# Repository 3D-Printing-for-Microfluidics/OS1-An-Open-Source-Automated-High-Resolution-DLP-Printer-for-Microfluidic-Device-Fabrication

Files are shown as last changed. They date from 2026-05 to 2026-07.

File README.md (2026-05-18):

# **OS1:** An Open-Source, Automated, High-Resolution DLP Printer for Microfluidic Device Fabrication

Open Source 1 (OS1), an open-source, high-resolution, DLP-based vat photopolymerization platform for fabricating microfluidic devices. Microfluidic function is defined by interconnected negative features, i.e., void regions that form channels, chambers, valves, and other fluidic elements within the printed structure. Accurately producing these features requires high optical resolution, uniform exposure, precise build-surface alignment, and reliable focus control. OS1 addresses these requirements in an automated platform derived from more than 10 years of custom DLP printer development for microfluidics. The printer enables rapid fabrication of microfluidic devices with complex three-dimensional negative-feature geometries that are difficult to achieve using traditional cleanroom-based methods. To reduce dependence on specialized hardware expertise and custom calibration tools, OS1 includes automatic build-surface planarization, automated focus calibration, active focus correction across the build area using a confocal displacement sensor, light-engine power correction using a fiber-optic photodiode sensor, and grayscale image correction for improved irradiance uniformity. These capabilities support repeatable, high-quality fabrication while making advanced microfluidic 3D printing more accessible to other research groups.

This repository is the home to the digital design files for the OS1's hardware, the standalone instruction manual, and the bill of materials.

## CAD

In the CAD folder, step files for the entire printer assmebly and each custom component are included. For parts that are FDM printed, a .3mf file is included. For aluminum parts and polycarbonate parts that are to be cut on a CNC waterjet, a .dxf "Tetris" layout file is included. There are also folders containing the design and manufacturing files for 2 custom printed circuit boards.

## Bill of Materials

The Bill of Materials is contained in a Microsoft Excel spreadsheet (.xlsx). It is oraganized into subassembly groups to match the instruction manual.

## Supplemental

The Visitech LRS WQ light engine utilized in this platform has been discontinued and replaced with an LRS WQ Plus light engine. This new version is not compatible with the current OS1 software and has not been validated with our platform; however, the full STEP assembly for the updated version and an alternate instruction manual are available in the supplemental information. Note on printer software: the LRS WQ Plus is a major revision of the LRS platform and uses a new communication protocol from the previous version. To implement the new LRS WQ Plus, a new hardware driver will need to be written which does not rely on HDMI data transfer from the Raspberry Pi.

Included in the supplemental materials is also a set of videos detailing specific parts of printer construction, operation, and maintenance.

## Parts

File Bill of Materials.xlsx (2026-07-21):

Subsystem | Designator | Component (Description) | Number | Cost Per Unit ($) | Total Cost ($) | Source of Materials | Total Cost
General Assembly |  | (Item #: ) |  |  |  |  | 69766.73
 | M6 x 16 Screws | Alloy Steel Socket Head Screw M6x16 (Item #: 91290A321) | 2 | 16.63 | 33.26 | https://www.mcmaster.com/91290A321/
 | M4 x 10 Button Head Screws | 316 Stainless Steel Button Head Hex Drive Screws (Item #: 94500A227) | 2 | 14.6 | 14.6 | https://www.mcmaster.com/94500A227/
 | M4 Hex Nut | Medium-Strength Steel Thin-Profile Hex Nut (Item #: 90695A035) | 1 | 2.73 | 2.73 | https://www.mcmaster.com/90695A035/
 | M2-M6 Assorted Screw and Nut Set | This contains assorted screws that will be used as fasteners in the 3D printer. Hapric 2160 Pcs Metric Screw Assortment Metric Bolts M2 M3 M4 M5 M6 Nuts and Bolt Kit, 12.9 Alloy Steel Black Zinc Plated Hex Socket Head Screws Nuts Bolts and Washers Set | 1 | 22.99 | 22.99 | https://a.co/d/07h6Lx55
 | 6061 Aluminum Block For Build Platform | 6061 Aluminum Block to be milled for Build Platform | 2 in x 2 in x 3 in (50.8 mm x 50.8 mm x 76.2 mm) | N/A |  | Online Metal Supplier or Local Metal Supplier
 | 6061 Aluminum Block For Resin Tray | 6061 Aluminum Block to be milled for Resin Tray | 1.5 in x 4.5 in x 7.5 in (38.1 mm x 114.3 mm x 190.5 mm) | N/A |  | Online Metal Supplier or Local Metal Supplier
 | 0.5" 6061 Aluminum | 0.5 inch (12.7mm) thick 6061 aluminum plate | 3.281 ft x 3.281 ft (1 m x 1 m), 10.765 ft^2 (1 m^2) | N/A | 500 | https://www.midweststeelsupply.com/store/6061aluminumplate
 | 18 Guage 6061 Aluminum Sheet | 18 guage (1 mm thick) 6061 aluminum sheet for fiber optic mounting plate | 35 mm x 35 mm |  |  | Online Metal Supplier or Local Metal Supplier
 | Invar Legs | INVAR Rod 0.75 Diameter x 12 in length | 6 | 76 | 456 | https://www.efineametals.com/controlled-expansion-alloys/invar-36-pernifer-36-nilo-36-invar-steel/invar-pernifer-nilo-36-rod-bar-sheet-plate/
 | M6 Spacers | Aluminum Unthreaded Spacer 13 mm OD, 4 mm Long, for M6 Screw Size (Item #: 94669A162) | 6 | 0.94 | 5.64 | https://www.mcmaster.com/94669A162/
 | DIN Rail | Steel DIN 3 Rail, 5-7/8" Length (Item #: 8961K86) | 1 | 4.47 | 4.47 | https://www.mcmaster.com/8961K86/
 | Hose Clamp | Worm-Drive Clamps for Firm Hose and Tube, Steel Screw, 1/2" Band Width, 1-1/16" to 2" Clamp ID (Item #: 5415K17) | 1 | 12.63 | 12.63 | https://www.mcmaster.com/5415K17/
Control Electronics
 | USB Hub | UGREEN USB 3.0 Hub, 4 Ports USB A Splitter Ultra-Slim USB Expander for Mouse, Keyboard, Flash Drive, U Disk, Printer Compatible with Laptop, Desktop PC, Xbox, PS5, and More | 1 | 6.96 | 6.96 | https://a.co/d/0eLZbc51
 | Ethernet Cables | Cable Matters 10Gbps 5-Pack Snagless Cat 6 Ethernet Cable - 5ft, Cat 6 Cable, Cat6 Cord, Ethernet Cord, Black | 4 | 14.99 | 14.99 | https://a.co/d/03ATOEky
 | USB-A to Micro USB Cables | Amazon Basics 2-Pack USB-A to Micro USB Cable, Data Transfer, Android Charger, 480Mbps Transfer Speed, Gold-Plated Plugs, USB 2.0, 3 Foot, Black | 2 | 7.99 | 7.99 | https://a.co/d/08tfeqxj
 | 2-pin MOLEX connectors | 2 Rectangular Connectors - Housings Receptacle White 0.100" (2.54mm) (Item #: 900-0022013027-ND) | 3 | 0.1 | 3 | https://www.digikey.com/short/2q20hb45
 | AWG Crimp | Non-Gendered Contact Tin 22-30 AWG Crimp (Item #: WM2623-ND) | 6 | 0.14 | 0.84 | https://www.digikey.com/short/h277nhrp
 | PCB Connector Header | Connector Header Through Hole 2 position 0.156" (3.96mm) (Item #: WM50008-02-ND) | 3 | 0.55 | 1.65 | https://www.digikey.com/short/j205fpr2
 | Raspberry Pi 5 | SBC 2.4GHZ 4 CORE 8GB PI 5 (Item #: 2648-SC1432-ND) | 1 | 175 | 175 | https://www.digikey.com/short/ft70prjf
 | Raspberry Pi Active Cooler | Heat Sink Raspberry Pi 5 Aluminum (Item #: 2648-SC1148-ND) | 1 | 5 | 5 | https://www.digikey.com/short/919jzb3j
 | NVMe Base | Pimoroni NVMe Base for Raspberry Pi 5 - PIM699 (Item #: 5845) | 1 | 19.95 | 19.95 | https://www.adafruit.com/product/5845
 | Raspberry Pi SSD | Kingston NV3 1TB M.2 2280 NVMe SSD, PCIe 4.0 Gen 4x4, Up to 6000 MB/s, SNV3S/1000G. NOTE: 1 TB is not necessary if you will not be doing a lot of printing. We have one because we needed the additional storage. | 1 | 164.99 | 164.99 | https://a.co/d/02vxUVt9
 | Raspberry Pi Power Supply | Official Raspberry Pi 27W PD Power Supply 5.1V 5A with USB C (Item #: 5814) | 1 | 14.04 | 14.04 | https://www.adafruit.com/product/5814
 | Teensy 4.0 | 4.0 (Headers) | 2 | 30.05 | 60.1 | https://www.amazon.com/Teensy-4-0-With-Pins/dp/B08259KDHY/ref=sr_1_3
 | PDU | StarTech.com 16 Outlet Horizontal 1U Rack Mount PDU Power Strip | 1 | 80.1 | 80.1 | https://www.amazon.com/StarTech-com-Rackmount-Outlets-Surge-Protection/dp/B003GSGNE0?th=1
 | Resistors | 4.7 kOhm and 10 kOhm resistor | 1 | 5.99 | 5.99 | https://a.co/d/08zMVh81
Enclosure
 | Enclosure Polycarbonate | Polycarbonate Clear Plastic Sheet 24" X 48 X 0.118 (1/8") | 1 | 47.22 | 47.22 | https://a.co/d/i2hpSBR
 | UV Film | HOHOFILM 60"x20" Colored Window Film Clear Decorative Glass Tint Sun Blocking Heat Control Self Adhesive Window Tint | 1 | 16.9 | 16.9 | https://a.co/d/div4S9N
 | Hinges | Mini Leaf Hinge (Item #: RPC2430-ND) | 5 | 3.35 | 16.77 | https://www.digikey.com/en/products/detail/essentra-access-solutions/129912/7688848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
 | Rubber Stopper | Load-Rated Adhesive-Back Sorbothane Bumper (Item #: 8215K215) | 2 | 7.6 | 15.2 | https://www.mcmaster.com/8215K215/
Resin Tray
 | M4 x 12, 90 degree | M4, coarse, 25, countersink, 90 degree (Item #: 91294A192) | 1 | 6.38 | 6.38 | https://www.mcmaster.com/91294a192/
 | Key Locking Inserts | 18-8 Stainless Steel Key-Locking Inserts with Thin Wall, M4 x 0.7 mm Thread, 5.25 mm Installed Length (Item #: 93715A345) | 5 | 12.46 | 49.9 | https://www.mcmaster.com/93715A345/
 | Kinematic Ball Mounts | uxcell 1/2-inch Ceramic Bearing Balls ZrO2 Zirconium Oxide Ball G5 Precision | 3 | 8.79 | 26.37 | https://a.co/d/8nKZhx9
 | Glass | Large Microscope Slides, 3 inx 4 in (Item #: #3040-50) | 1 | 97.5 | 97.5 | https://brainresearchlab.com/product/large-slides/
 | Clamps | Low-Profile Hold-Down Toggle Clamp (Item #: 5091A11) | 2 | 15.2 | 30.4 | https://www.mcmaster.com/5091A11/
 | O-Rings | Chemical-Rst Viton® Fluoroelastomer O-Ring Super-Resilient, 2 mm Wide, 94 mm ID (Item #: 1295N282) | 1 | 6.44 | 6.44 | https://www.mcmaster.com/1295N282/
 | Torque Screw-Driver | Screw driver for resin tray screws (Item #: 431-28413-ND) | 1 | 137.98 | 137.98 | https://www.digikey.com/en/products/detail/wiha/28413/10126229?s=N4IgTCBcDaICwGYCMBaMAOOSEoHIBEQBdAXyA
 | Blade Hex | Blad Hex for screw driver: 2.5MM 6.89" (Item #: 431-1302-ND) | 1 | 8.98 | 8.98 | https://www.digikey.com/en/products/detail/wiha/28547/1987925
 | Squeegee For Film Application | 4 Inch Mini Squeegee Silicone Squeegee with Rubber Water Blade, Anti-Slip Handle | 1 | 10.55 | 10.55 | https://a.co/d/0cAwyj2l
Build Platform
 | Planarization Screw | Alloy Steel Socket Head Screw Black-Oxide, M4 x 0.7 mm Thread, 110 mm Long (Item #: 91290A575) | 1 | 9.33 | 9.33 | https://www.mcmaster.com/catalog/131/3556/91290A575
 | Rivet Nut | Stainless Steel Twist-Resistant Rivet Nuts (Item #: 97467a666) | 1 | 8.07 | 8.07 | https://www.mcmaster.com/catalog/131/3790/97467A666
 | Alignment Pins | Linear Motion Shaft-- needs to be cut to size. (Item #: 1031K61) | 1 | 10.28 | 10.28 | https://www.mcmaster.com/catalog/131/1375/1031K61
 | M5 Alignment Screws | 18-8 Stainless Steel Low-Profile Socket Head Screws (Item #: 92855A528) | 1 | 12.71 | 12.71 | https://www.mcmaster.com/catalog/131/3574/92855A528
 | 5 mm Shaft Diameter Flanged Bearings | Flanged Sleeve Bearings (Item #: 2934T111) | 4 | 8.63 | 34.52 | https://www.mcmaster.com/catalog/131/1453/2934T111
 | 0.5 mm Brass Ring Shim | 0.5 mm Thick, 6 mm ID (Item #: 92678A631) | 1 | 10.3 | 10.3 | https://www.mcmaster.com/catalog/131/3720/92678A631
 | 0.2 mm Brass Ring Shim | 0.2 mm Thick, 6 mm ID (Item #: 92678A611) | 2 | 8.03 | 16.06 | https://www.mcmaster.com/catalog/131/3720/92678A611
 | Springs | 0.625" Long, 0.360" OD, 0.290" ID (Item #: 9657K656) | 1 | 13.16 | 13.16 | https://www.mcmaster.com/9657K656/
 | 5/32" Shaft Diameter Bronze Bearing | High-Strength 932 Bronze Flanged Sleeve Bearing for 5/32" Shaft Diameter and 1/4" Housing ID, 3/8" Long (Item #: 7815K804) | 1 | 19.3 | 19.3 | https://www.mcmaster.com/7815K804/
 | 0.2 mm Brass Shim Washer | 260-360 Brass Shim 0.2 mm Thick, 6 mm ID (Item #: 92678A611) | 2 | 8.03 | 16.06 | https://www.mcmaster.com/93715A345/
 | 0.5 mm Brass Shim Washer | 260-360 Brass Shim 0.5 mm Thick, 6 mm ID (Item #: 92678A631) | 1 | 10.3 | 10.3 | https://www.mcmaster.com/92678A631/
 | JB-Weld | J-B Weld 8265S Original Cold-Weld Steel Reinforced Epoxy - 2 oz. | 1 | 6.49 | 6.49 | https://a.co/d/09OcuKCe
Motion Stages
 | X-Stage | 150 mm Linear Translation Stage with Integrated Controller, Stepper Motor (Item #: LTS150C/M) | 1 | 3392.5 | 3392.5 | https://www.thorlabs.com/newgrouppage9.cfm?objectgroup_id=3961&pn=LTS150C/M#8110
 | Y-Stage | 300 mm Linear Translation Stage with Integrated Controller, Stepper Motor (Item #: LTS300C/M) | 1 | 3847.57 | 3847.57 | https://www.thorlabs.com/newgrouppage9.cfm?objectgroup_id=7652&pn=LTS300C/M#8109
 | Focus Stage | 25 mm (0.98") Low-Profile Motorized Translation Stage (Item #: MTS25/M-Z8) | 1 | 1177.03 | 1177.03 | https://www.thorlabs.com/newgrouppage9.cfm?objectgroup_id=3423&pn=MTS25/M-Z8#3005
 | Griffin Z-Stage with Power Supply and Galil Controller | LNS linear stage, 100mm travel, brushless servo motor, sinusoidal (Item #: LNS-100) | 1 | 6500 | 6500 | https://www.griffinmotion.com/shop/lns-100
 | X/Y Adapter Plate | XY Adapter Plate for LTS150C/M, LTS300C/M, LTS450C/M, or LTS600C/M Stages (Item #: LTSP1/M) | 1 | 89.61 | 89.61 | https://www.thorlabs.com/item/LTSP1_M
Auto Planarization
 | DC motor driver | MP6550 Single Brushed DC Motor Driver Carrier (Item #: 4733) | 1 | 5.95 | 5.95 | https://www.pololu.com/product/4733
 | Planarization motor | 227:1 Metal Gearmotor 25Dx56L mm MP 12V (Item #: 3233) | 1 | 33.95 | 33.95 | https://www.pololu.com/product/3233
 | Planarization Gears | 2303 Series Steel, MOD 0.8 Pinion Gear (4mm Round Bore, 15 Tooth) (Item #: 2303-0004-0015) | 2 | 9.95 | 19.89 | https://www.servocity.com/2303-series-steel-mod-0.8-pinion-gear-4mm-round-bore-15-tooth-/
 | Motor Bracket | 25D mm Metal Gearmotor Bracket Pair (Item #: 2676) | 1 | 10.95 | 10.95 | https://www.pololu.com/product/2676
Loadcell
 | 15 kg loadcell | ANYLOAD 108BA Aluminum Single Point Load Cell (Item #: 108BA) | 1 | 86 | 86 | https://tacunasystems.com/products/load-cells/single-point/anyload-108ba-aluminum-single-point-load-cell/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
 | Amplifier | (Item #: FSH03863) | 1 | 715 | 715 | https://www.futek.com/configure/advanced/fsh03863/1/0
 | Amplifier Power supply | (Item #: FSH04448) | 1 | 120 | 120 | https://www.futek.com/store/accessories/instrument-accessories/fsh04448
Tip-Tilt Assembly
 | Tip/Tilt Motors | 12 mm Travel DC Servo Motor Actuators (Item #: Z912) | 2 | 938.6 | 1877.2 | https://www.thorlabs.com/newgrouppage9.cfm?objectgroup_id=1882&pn=Z912#2497
 | Tip/Tilt Stage | KM200B/M - 73.7 mm x 73.7 mm Kinematic Platform Mount (Item #: KM200B/M) | 1 | 122.03 | 122.03 | https://www.thorlabs.com/thorproduct.cfm?partnumber=KM200B/M
 | K-Cubes | K-Cube Brushed DC Servo Motor Controller (Item #: KDC101) | 3 | 826.75 | 2480.25 | https://www.thorlabs.com/newgrouppage9.cfm?objectgroup_id=2419&pn=KDC101
 | K-Cube Dock | K-Cube USB Controller Hub (Item #: KEH3) | 1 | 662.5 | 662.5 | https://www.thorlabs.com/item/KEH3
 | Mirror | 75mm Square UV Enhanced Aluminum Coated, λ/10 Mirror (Item #: #84-426) | 1 | 360.4 | 360.4 | https://www.edmundoptics.com/p/75mm-square-uv-enhanced-aluminum-coated-lambda10-mirror/27522/
 | Keyence Sensor | Sensor head (70 mm ・Focused spot type) (Item #: CL-P070) | 1 | 2100 | 2100 | https://www.keyence.com/products/measure/laser-1d/cl-3000/models/cl-p070/?search_dl=1
 | Keyence Optical Unit | Optical unit (70 mm ・Focused spot type) (Item #: CL-P070N) | 1 | 4800 | 4800 | https://www.keyence.com/products/measure/laser-1d/cl-3000/models/cl-p070n/?search_dl=1
 | Keyence Sensor Controller | Ultra-compact switch-mode power supply (Item #: CL-3000) | 1 | 4300 | 4300 | https://www.keyence.com/products/measure/laser-1d/cl-3000/models/cl-3000/?search_dl=1
 | Keyence Power Supply | Ultra-compact switch-mode power supply (Item #: CA-U4 (CA-U4#)) (Power Supply Cable Item #: OP-99025) | 1 | 320 | 320 | https://www.keyence.com/products/measure/laser-2d/lj-s8000/models/ca-u4/?search_dl=1
 | Sticky Foam Tape | 3M 4032 Double Coated Urethane Foam Tape, Bonding, Attaching, Mounting, White, 0.5 in x 5 yd, 1 Roll | 1 | 8.29 | 8.29 | https://a.co/d/7Shym37
Photo Diode
 | Photodiode Sensor | Silicon Fiber Power Head, 350-1100nm, 5mW (Item #: S150C) | 1 | 381.34 | 381.34 | https://www.thorlabs.com/thorproduct.cfm?partnumber=S150C
 | USB Interface | USB Power and Energy Meter Interface (Item #: PM100USB) | 1 | 532.59 | 532.59 | https://www.thorlabs.com/thorproduct.cfm?partnumber=PM100USB
 | Bifurcated Fiber | Bifurcated Fiber Bundle, Ø50/125 Fiber, High OH, SMA, L=2m (Item #: BFY50HS02) | 1 | 474.23 | 474.23 | https://www.thorlabs.com/thorproduct.cfm?partnumber=BFY50HS02
 | Fiber Optic Adapter | Fiber Optic Connectors ADAPTER, SMA HALF-LENGTH (Item #: 523-905-120-5004) | 1 | 5.99 | 5.99 | https://www.mouser.com/ProductDetail/Amphenol-Fiber-Optics/905-120-5004-P?qs=7%2F6SraaimPRtTpADennAWQ%3D%3D
Light Engine
 | Light Engine | LRS WQ, 365 nm LED | 1 |  | 20000 | https://visitech.com/additive-manufacturing/
 | Lens Barrel | Pl LRS 1.0 HC | 1 |  | 5000 | https://visitech.com/additive-manufacturing/
 | Asahi Shortpass Filter | Special Order. 270 nm shortpass spectra filter, 50mm diameter. | 1 |  | 800 | https://www.asahi-spectra.com/opticalfilters/shortpass_filters.asp
Curing Tower and Prep Materials
 | 430 nm LED | 430 nm, 529.2 mW (Min) LED on Metal-Core PCB, 500 mA (Item #: M430D3) | 1 | 97.63 | 97.63 | https://www.thorlabs.com/item/m430d3
 | LED Heat Sink | HEATSINK ALUM ANOD 30x50mm (Item #: AE10889-ND) | 1 | 0.94 | 0.94 | https://www.digikey.com/short/mw3c5rm4
 | Resistor Heat Sink | ALUMINIUM HEAT SINK 30X30MM (Item #: 1168-TGH-0300-04-ND) | 1 | 2.52 | 2.52 | https://www.digikey.com/short/jbtb9hcb
 | High Power Resistor | RES CHAS MNT 30 OHM 1% 50W (Item #: KAL50FB30R0-ND) | 1 | 5.99 | 5.99 | https://www.digikey.com/short/0mvz44j0
 | Power Switch | SWITCH SLIDE DPDT 1A 125V (Item #: 563-1566-ND) | 1 | 1.39 | 1.39 | https://www.digikey.com/short/ncqvrphf
 | Wall Power Adapter | AC/DC WALL MOUNT ADAPTER 12V 6W (Item #: 839-16-00030-ND) | 1 | 6.77 | 6.77 | https://www.digikey.com/short/2cvj0zjh
 | Aluminum Tape | Reflective Aluminum Tape 2"x 65Feet,3.9mil | 1 | 6.99 | 6.99 | https://a.co/d/0b4TpmpP
 | Thermal Glue | G109 10gram Thermal Conductive Glue | 1 | 7.99 | 7.99 | https://a.co/d/074KhLvI
 | Heat Shrink Tubing | Heat Shrink Tubing for 24 Guage Wire | 3 |  |  | Local Hardware
 | 24 Guage Wire | 24 awg Silicone Electrical Wire Cable 2 Colors (30ft Each) | 1 | 7.98 | 7.98 | https://a.co/d/0ffXFZsn
 | Glass Slide Staining Dish with Lid | Rectangular Slotted Glass Slide Staining Dish with Lid. 20 Slide Capacity for Silinizing glass slides. (Item #: 2626M2) | 1 | 29 | 29 | https://www.medicus-health.com/histology/glass-slide-staining-dish-with-lid.html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
Optical Table (Optional But Recommended)
 | Racks | 19" Rack Chassis for Optical Table Workstations (Item #: TFR19) | 1 | 259.29 | 259.29 | https://www.thorlabs.com/thorproduct.cfm?partnumber=TFR19
 | Pressure Regulator | Air Filter / Regulator (Item #: PTA013) | 1 | 94.71 | 94.71 | https://www.thorlabs.com/thorproduct.cfm?partnumber=PTA013
 | Breadboard (tabletop) | Nexus Breadboard, 30" x 36" x 4.3", Sealed 1/4"-20 Mounting Holes (Item #: B3036U) | 1 | 1975.8 | 1975.8 | https://www.thorlabs.com/thorproduct.cfm?partnumber=B3036U
 | Isolation Base | 700 mm (27.5") Active Isolation Frame 750 x 900 mm (30" x 36") (Item #: PFA51505) | 1 | 3247.41 | 3247.41 | https://www.thorlabs.com/thorproduct.cfm?partnumber=PFA51505
Consumables
 | SCOTCH Permanent Double Sided Tape | Scotch Double-Sided Tape, 1/2 in x 250 in (12.7 mm x 6.35 m), 3 Pack | 1 | 6.78 | 6.78 | https://a.co/d/0eu2PIkM
 | PEC PADs | PEC-PAD Lint Free Wipes 4”x4” Non-Abrasive Ultra Soft Cloth for Cleaning Sensitive Surfaces like Camera, Lens, Filters, Film, Scanners, Telescopes, Microscopes, Binoculars. (100 Sheets Per/Pkg) 4-Pack | 1 | 43.99 | 43.99 | https://a.co/d/03WTay2g
 | FEP Film | Special Order. CS hyde company 5 mil. FEP tape w/ 1 mil 3M8211 Optically Clear Acrylic adhesive, 24" x 24" (23.5" Useable due to adhesive width). | 1 | 166.3 | 166.3 | https://cshyde.com/
 | Box Cutters (Razor Blades) | JETMORE Single Edge Razor Blades, 50 Pack High Carbon Steel Razor Blades for Scraper, Sharp Utility Blades for Removing Glue, Stickers, Labels, Paint, Glass, Safety Razor Blades Individually Wrapped | 1 | 4.95 | 4.95 | https://a.co/d/02zaERS7
 | Glass Slides | VWR® Premium VistaVision™ Plain Microscope Slides, 1.0 mm, 3×1" (Item #: 16004-430) | 1 | 55.94 | 55.94 | https://www.vwr.com/us/en/product/NA1277058/vwr-premium-vistavision-plain-and-frosted-microscope-slides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
 | PEGDA | Resin Monomer (Item #: 475629) | 500mL | 172 | 172 | https://www.sigmaaldrich.com/US/en/product/aldrich/475629
 | Avobenzone | UV Absorber (Item #: 70356-09-1) | 100g | 141 | 141 | https://www.tcichemicals.com/US/en/search/?text=70356-09-1
 | NPS | Photoinitiator (Item #: 4171-83-9) | 25g | 303 | 303 | https://www.tcichemicals.com/US/en/p/N0744
 | Irgacure-819 | Photoinitiator (Item #: 511447) | 50g | 253 | 253 | https://www.sigmaaldrich.com/US/en/product/aldrich/511447
 | Silene | Glass slide preparation. (Item #: M6514) | 50mL | 111 | 111 | https://www.sigmaaldrich.com/US/en/product/sigma/m6514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
 | Toluene | Glass slide preparation. (Item #: 179418) | 1L | 93.1 | 93.1 | https://www.sigmaaldrich.com/US/en/product/sigald/179418
 | Kimwipes | Kimtech 34155 KIMWIPES, Delicate Task Wipers, 1-Ply, 4 2/5 x 8 2/5, 286/Box | 1 | 7.31 | 7.31 | https://a.co/d/0afGXSdW
 | IPA | --- | --- |  | --- | ---
 | Acetone | --- | --- |  | --- | ---
Safety
 | UV safety goggles | LG6, Laser Safety Glasses, Clear Lenses, 93% Visible Light Transmission, Universal Style | 1 | 190.59 | 190.59 | https://www.thorlabs.com/item/LG6

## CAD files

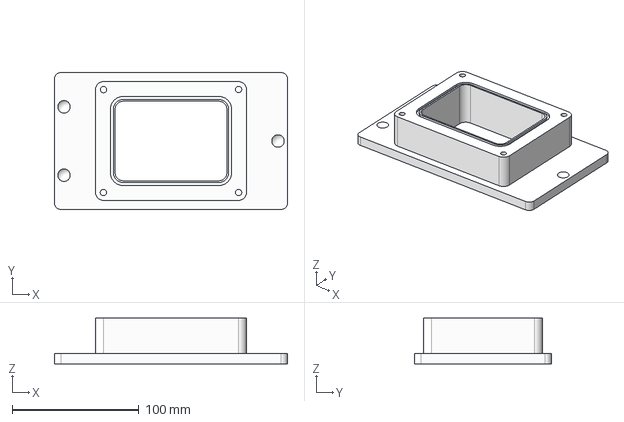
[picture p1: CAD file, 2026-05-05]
CAD/Resin Tray Main Body.step
184.0 x 108.0 x 36.0 mm

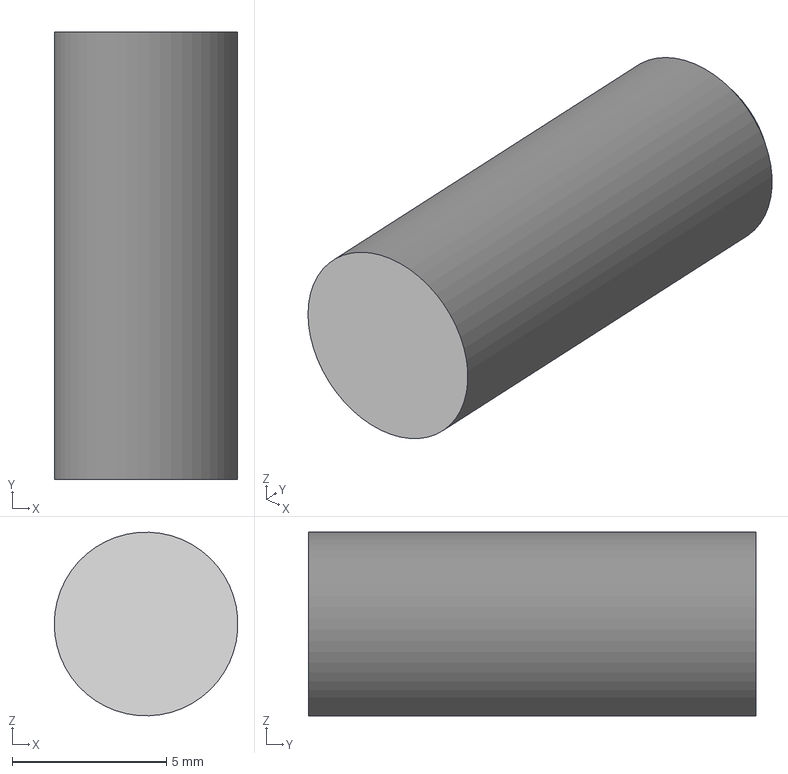
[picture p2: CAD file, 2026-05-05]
CAD/Alignment Pin.step
5.94 x 15.0 x 5.95 mm

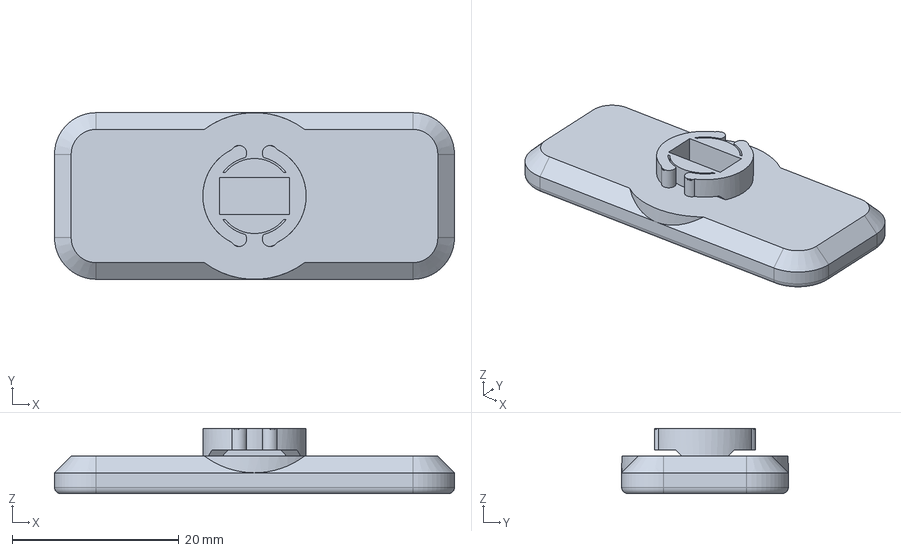
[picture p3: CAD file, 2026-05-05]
CAD/Clasp Back.step
48.0 x 20.0 x 7.83 mm

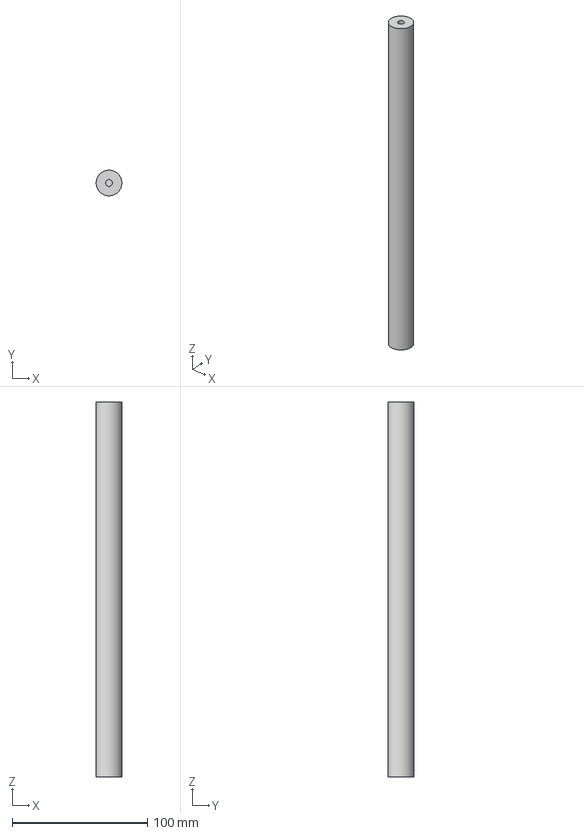
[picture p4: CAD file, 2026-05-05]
CAD/Leg.step
19.0 x 19.0 x 277.6 mm

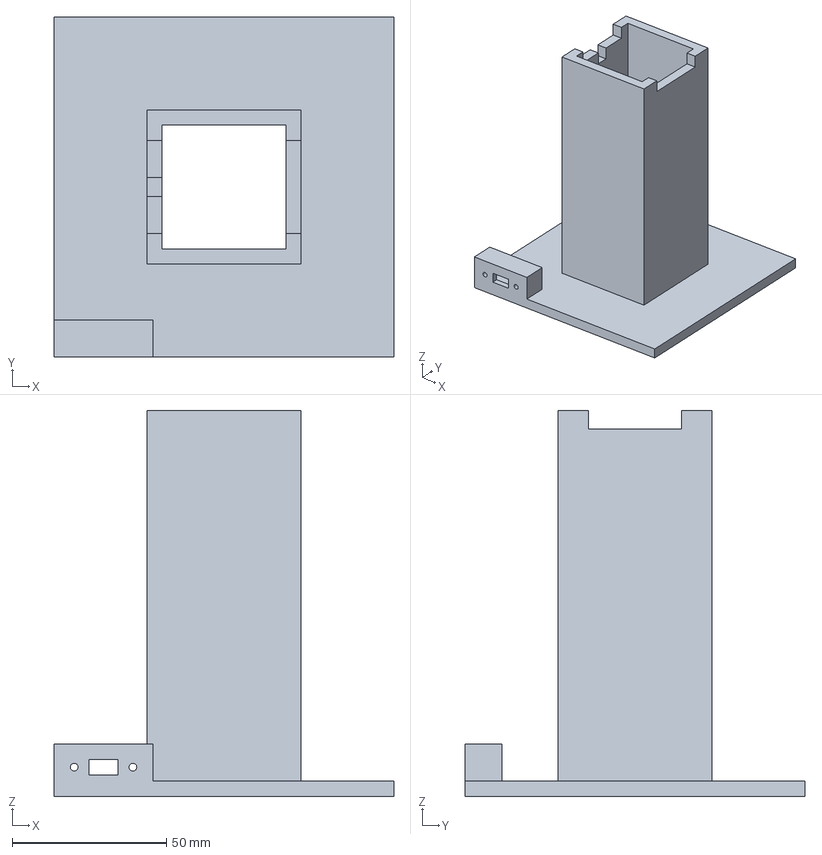
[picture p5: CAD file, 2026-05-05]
CAD/Curing Tower.step
110.0 x 110.0 x 125.0 mm

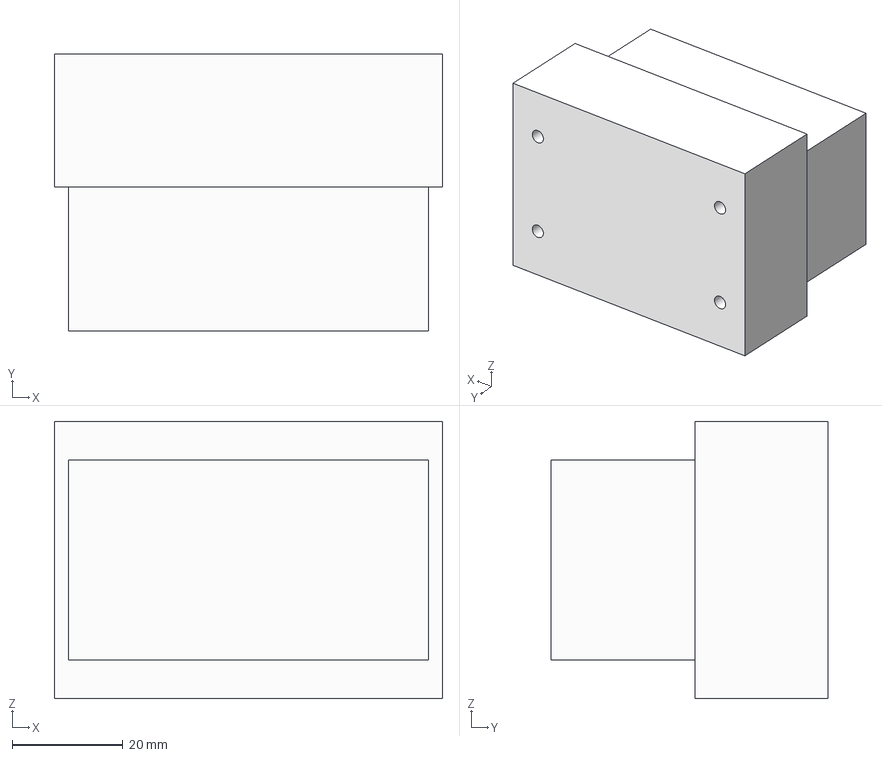
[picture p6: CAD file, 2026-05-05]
CAD/Build Platform.step
70.0 x 50.0 x 50.0 mm

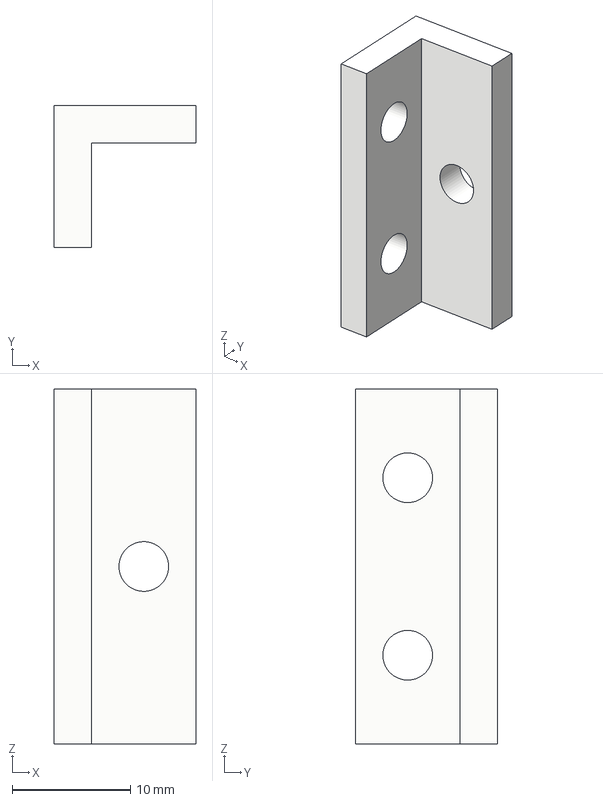
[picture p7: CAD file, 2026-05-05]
CAD/Enclosure Bracket.step
12.0 x 12.0 x 30.0 mm

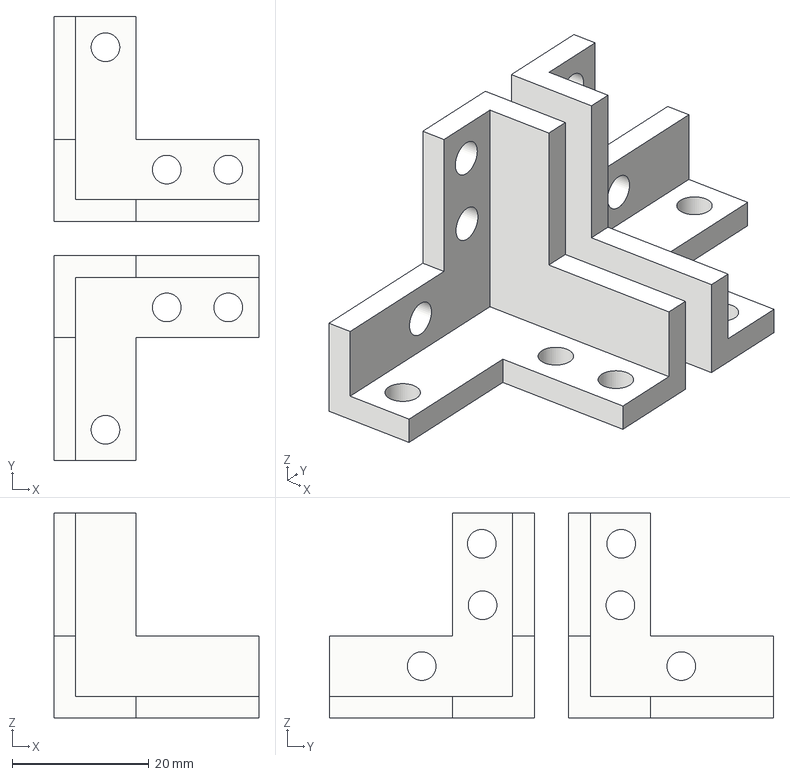
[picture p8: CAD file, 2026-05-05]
CAD/Corner Enclosure Bracket.step
30.0 x 65.0 x 30.0 mm
Bracket Left Corner
Bracket Right Corner

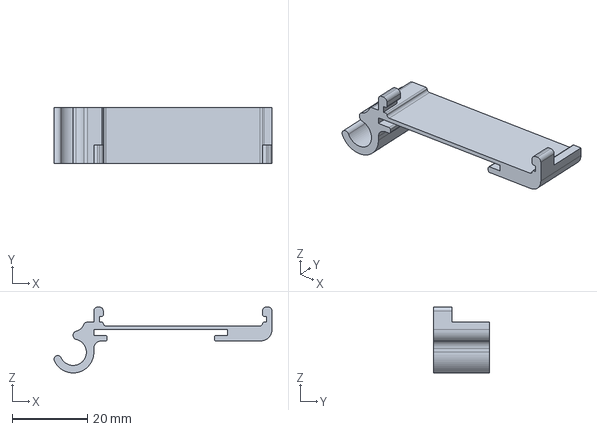
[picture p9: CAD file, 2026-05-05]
CAD/DIN Rail Mount.step
57.9 x 15.0 x 17.5 mm

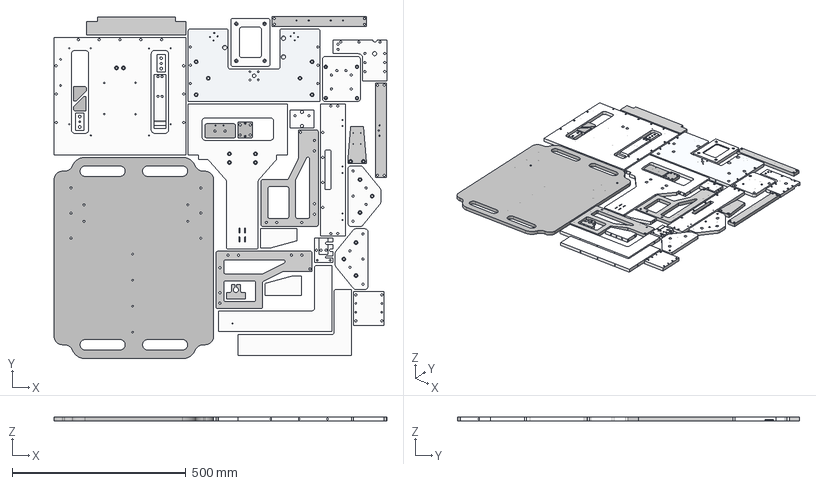
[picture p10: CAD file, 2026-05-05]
CAD/Printer Tetris Final.step
959.1 x 986.0 x 12.7 mm
Build Platfrom Right Clamp Plate
Build Platfrom Left Clamp Plate
Z-Stage Load Cell to Z-Stage Adapter Plate
Z-Stage Front Stiffening Bracket
Z-Stage Griffin Stage Plate
Z-Stage Left Stiffening Bracket
Z-Stage Right Stiffening Bracket
Z-Stage Build Platform Connection Plate
Z-Stage Planarization Motor Mount
Y-Axis Standoff Plate
Y-Axis Base Plate
Tip/Tilt Focus Standoff
Tip/Tilt Mount Leg 1
Tip/Tilt Mount Leg 2
Tip/Tilt Mount Plate
Light Engine Mount Front Right Bracket
Light Engine Mount Front Left Bracket
Light Engine Right Support
Light Engine Left Support
Light Engine Mount Top Bracket
Base Assembly Base Plate
Base Assembly Foot 1
Base Assembly Foot 2
Resin Tray Glass Clamp
Box Assembly Right Side Bracket
Box Assembly Top Plate
Box Assembly Support Back Plate
Box Assembly Left Side Bracket
Box Assembly Base Plate
Box Assembly Keyence Sensor Mount
Build Platform Slider Joint Plate
Envelope1(Qty: 1)

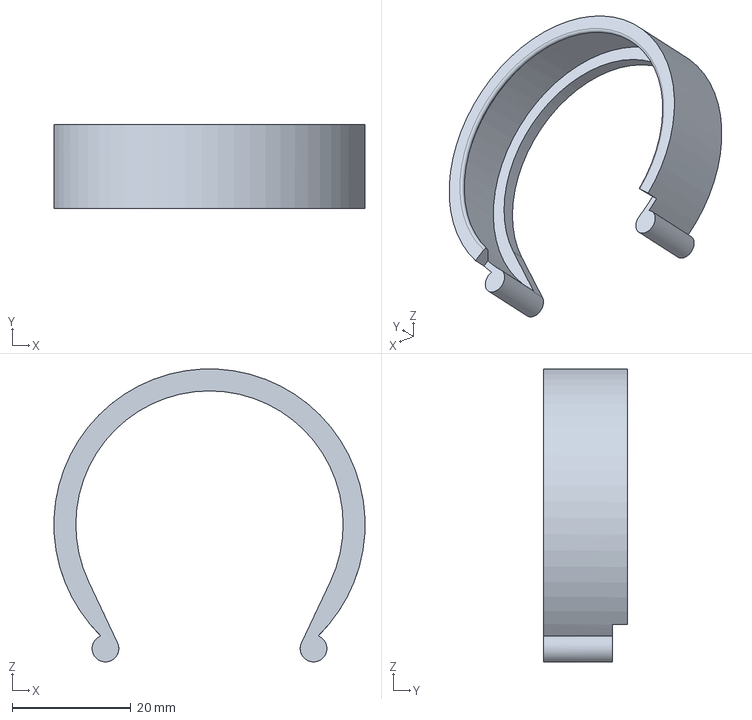
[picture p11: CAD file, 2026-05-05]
CAD/Asahi Mount.step
52.4 x 14.1 x 49.3 mm

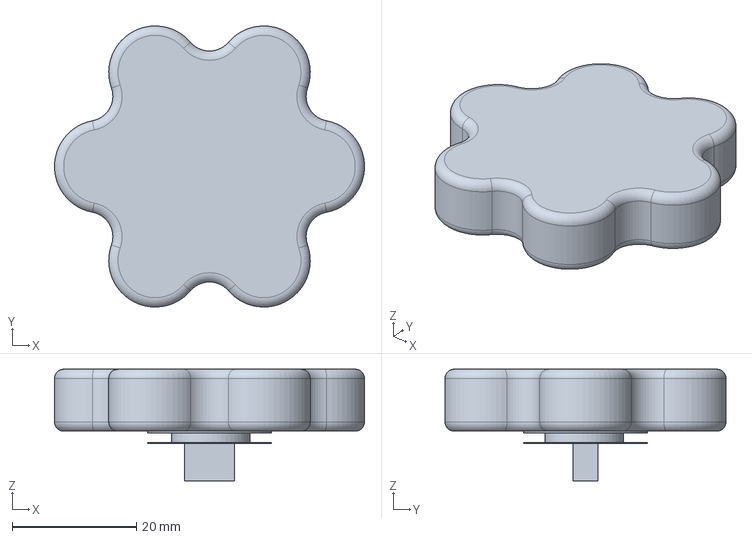
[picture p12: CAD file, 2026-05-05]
CAD/Clasp Handle.step
50.0 x 45.3 x 18.0 mm

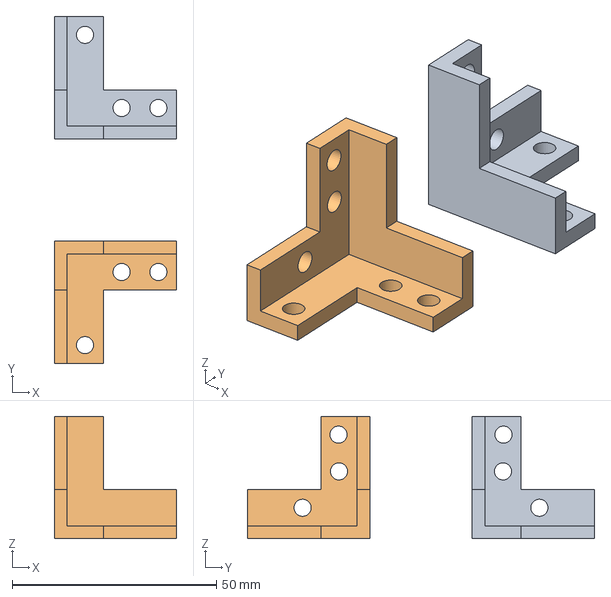
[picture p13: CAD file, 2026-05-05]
CAD/Corner Enclosure Brackets.3mf
30.0 x 85.0 x 30.0 mm

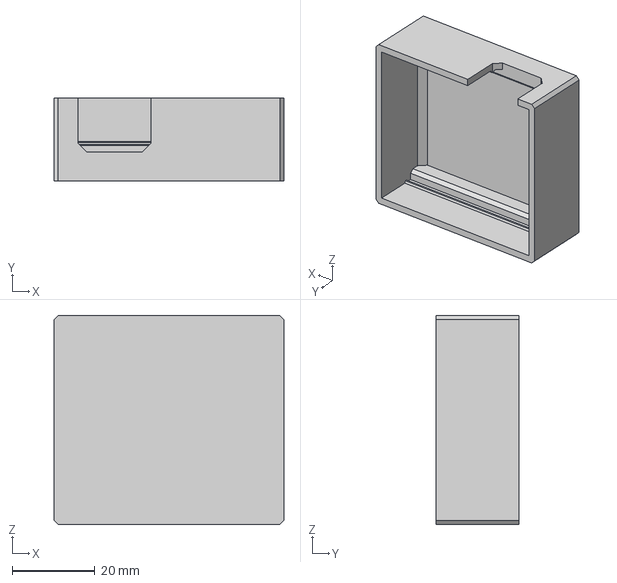
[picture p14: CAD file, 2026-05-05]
CAD/Planarization PCB Enlcosure.3mf
55.5 x 20.0 x 50.5 mm

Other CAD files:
CAD/Enclosure Tetris Final v1.step
CAD/Fiber Optic Mounting Plate.step
CAD/Resin Tray Glass Clamp.step
CAD/5 mm Allen Key Holder.step
CAD/5 mm Allen Key Holder.3mf
CAD/Asahi Mount.3mf
CAD/Build Platform Steel Bracket.step
CAD/Clasp Back.3mf
CAD/Clasp Handle.3mf
CAD/Curing Tower.3mf
CAD/DIN Rail Mount.3mf
CAD/Enclosure Bracket.3mf
CAD/Enclosure Tetris DXF.dxf
CAD/Planarization PCB Enclosure.step
CAD/Printer Tetris DXF.dxf

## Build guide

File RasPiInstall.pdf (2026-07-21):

# How to do a full install of an OS1 Raspberry Pi

## Purpose: This should walk through the install of a new Raspberry Pi 5 and NVME Hat with

Raspberry Pi OS (64-bit) 2024-03-15 for an OS1 3D printer.

## Physical setup

We are using a Raspberry Pi 5, a Pimoroni NVME base (https://shop.pimoroni.com/products/nvme-base?variant=41219587211347) and a Crucial P3 Plus 1TB SSD.

You can follow the tutorial here (https://learn.pimoroni.com/article/getting-started-with-nvme-base) to install the SSD and hat.

## Flashing Raspberry Pi OS

Download Raspberry Pi Imager
Connect NVME Drive to computer using external SSD housing In Raspberry Pi Imager
Select "Raspberry Pi 5" as device type
Select "Raspberry Pi OS (other)"
Select "Rapsberry Pi OS (Legacy 64-bit)" Debian Bookworm based Select NVME as storage location
Customize the OS
Set hostname (ie. "OS1")
Set timezone to your local timezone Set username (pi) and password Set up WiFi credentials
Enable SSH
You may also need an SD card on the first boot before we set the boot order in the EEPROM.

## System setup

## Configuring SSD

https://www.jeffgeerling.com/blog/2023/nvme-ssd-boot-raspberry-pi-5

Edit /boot/firmware/config.txt

Add to bottom of /boot/firmware/config.txt
dtparam=pciex1

Edit the EEPROM on the Raspberry Pi 5.

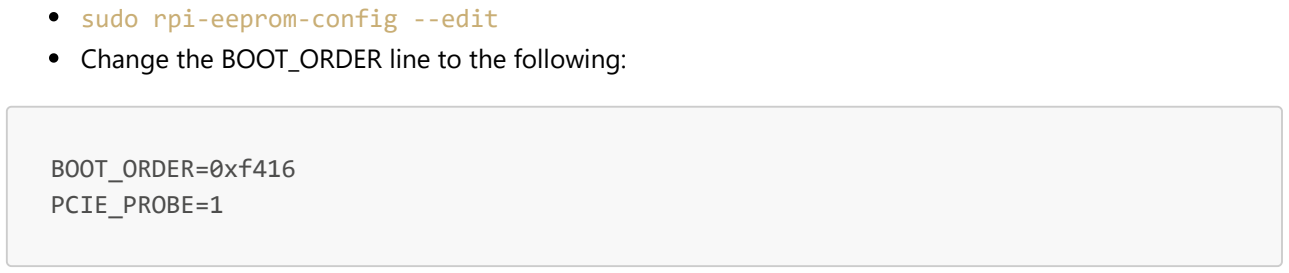
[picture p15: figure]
sudo rpi-eeprom-config --edit; BOOT_ORDER=0xf416 PCIE_PROBE=1

Change the BOOT_ORDER line to the following:

RasPiInstall.md | 2026-07-21

Press Ctrl-O, then enter, to write the change to the file. Press Ctrl-X to exit nano (the editor).

## Setting Clock

To connect to the internet you may have to update the system clock to be accurate. This can be done using the date command

date -s '2014-12-25 12:34:56' (with the accurate date and time)

## Connecting to Wifi

Wifi connection can be handled using the Raspberry Pi OS by connecting the Pi to a keyboard, mouse, and monitor. You may need to work with your institution's IT department to obtain a secure connection to the proper network.

## Disable wifi power saving mode

Run the following command in the terminal

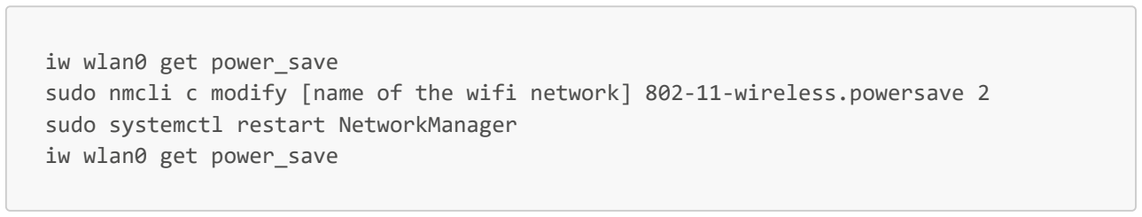
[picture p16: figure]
iw wlan0 get power_save; sudo systemctl restart NetworkManager iw wlan0 get power_save

sudo nmcli c modify [name of the wifi network] 802-11-wireless.powersave 2

Note: if you set up WiFi within the Raspberry Pi Imager, the name of the network will be "preconfigured".

## Setting up static ethernet address

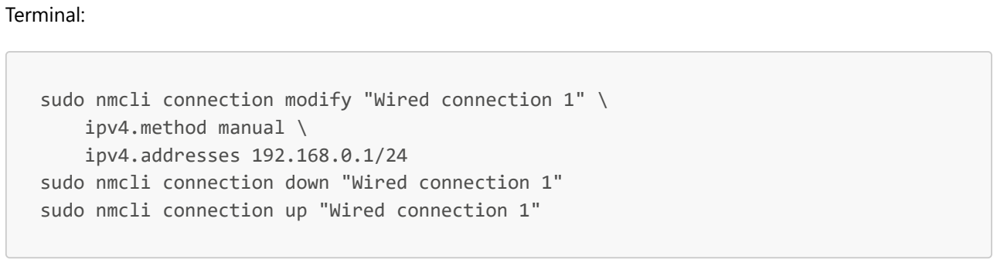
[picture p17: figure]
Terminal:; ipv4.method manual \ ipv4.addresses 192.168.0.1/24

sudo nmcli connection modify "Wired connection 1" \

sudo nmcli connection down "Wired connection 1" sudo nmcli connection up "Wired connection 1"

## Switching to legacy X11

In bookworm, X11 is deprecated in favor of wayland/wayfire. We need to swap back to X11 for proper light engine functionality.

sudo raspi-config
Select Advanced Options
Select Wayland
Select X11

## Disable screen blanking

If we do not disable screen blanking, the HDMI output will shutoff to save power. The light engines are not compatible with this behavior. To do this:

sudo raspi-config
Select Display Options
Select Screen Blanking
Select No

## Set USB rules

We need to set the USB permissions for several USB devices. To discover the information on these devices, you can use the lsusb command with the usb device connected to the pi. This will list the Bus, Device, VendorID:ProductID, and the common name. We just care about the vendor and product ids. We make a udev rule for each usb device that requires it.

sudo nano /etc/udev/rules.d/99-thorlabspm100.rules

add
SUBSYSTEM=="usb",ATTRS{idVendor}=="1313",ATTRS{idProduct}=="8072",GROUP="users",MOD E:="0666"

Reload udev

sudo udevadm control --reload-rules

## Fix Journaling

You also need to update the journal config (retention length and segmentation) at /etc/systemd/journald.conf

[Journal]
#Storage=auto

#Compress=yes

#Seal=yes

#SplitMode=uid

#SyncIntervalSec=5m

#RateLimitIntervalSec=30s

#RateLimitBurst=10000

#SystemMaxUse=

#SystemKeepFree=

#SystemMaxFileSize=

#SystemMaxFiles=100

#RuntimeMaxUse=

#RuntimeKeepFree=

#RuntimeMaxFileSize=

#RuntimeMaxFiles=100

MaxRetentionSec=1week
MaxFileSec=1day
#ForwardToSyslog=yes

#ForwardToKMsg=no

#ForwardToConsole=no

#ForwardToWall=yes

#TTYPath=/dev/console

#MaxLevelStore=debug

#MaxLevelSyslog=debug

#MaxLevelKMsg=notice

#MaxLevelConsole=info

#MaxLevelWall=emerg

#LineMax=48K

#ReadKMsg=yes

We are changing the MaxRetentionSec and MaxFileSec sections. For this to work properly, you also need to create the journal logging directory. Without these commands the old journals are not perserved

## Downloading Repo

## Installing 3d_printer_control software

## Setup Virtual Environment

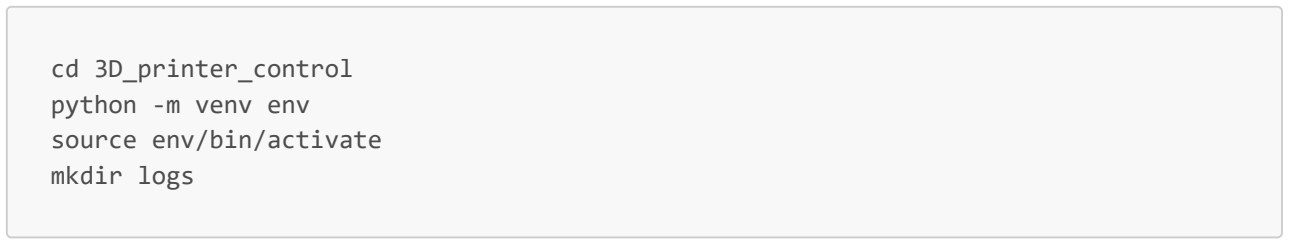
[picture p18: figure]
cd 3D_printer_control python -m venv env source env/bin/activate mkdir logs

## Upgrade pip and setuptools

## Create .env File

In the 3d_printer_control root, create the .env file

and add the following variables with corresponding values:

ADMIN_PASSWORD= [your admin password]
OPEN_ACCESS=True (allow anyone who makes an account to have access to all features except user management)
OPEN_REGISTRATION=True (allow anyone to make a new account) SESSION_EXPIRATION_MINUTES=60 (how long a session lasts when left idle)

LOGIN_EXPIRATION_MINUTES=10 (how long an individual login instance lasts if open access is True)
REMEMBER_COOKIE_DURATION_DAYS=7 (how long cookies are remembered)

The following variables are optional, but if left blank, will diable account recovery and session reminder emails.

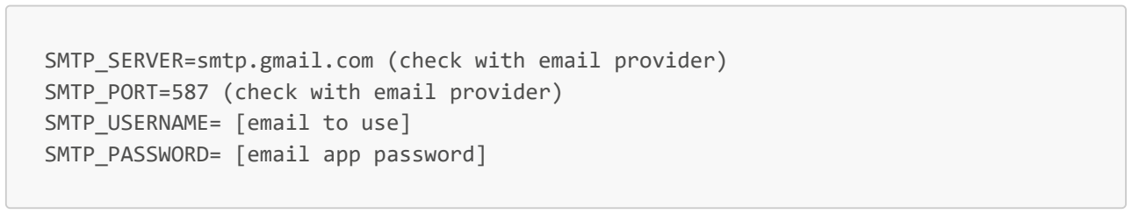
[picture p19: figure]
SMTP_SERVER=smtp.gmail.com (check with email provider) SMTP_PORT=587 (check with email provider) SMTP_USERNAME= [email to use] SMTP_PASSWORD= [email app password]

## Install Galil Driver

Instruction on installing the galil driver are found here but the important parts are below. https://www.galil.com/raspberrypi and maybe here https://www.galil.com/sw/pub/all/doc/gclib/html/. Note: a known working copy of the driver is included in the code repository. It can be installed as follows.

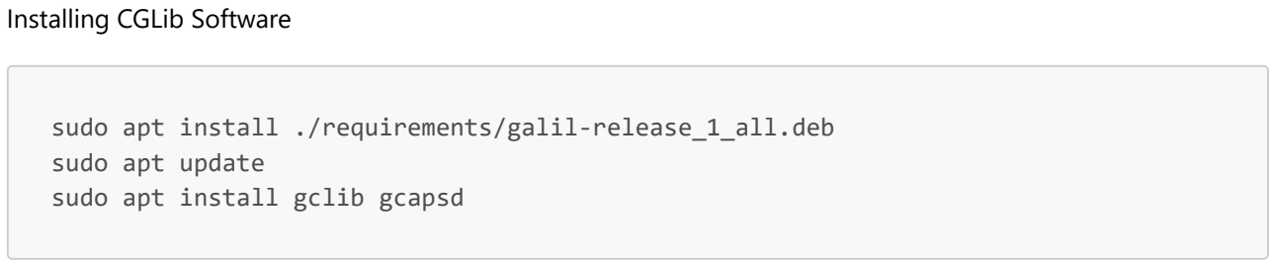
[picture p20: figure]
Installing CGLib Software; sudo apt install ./requirements/galil-release_1_all.deb sudo apt update sudo apt install gclib gcapsd

## Install Python Packages

pip install -r requirements/dev.txt

## Setup Flask Database

From the 3D_printer_control directory run the following: source rpi/flask_db_setup.sh

## Setup Systemd Service

Give the user authorization to access the X server

Create the systemd service with sudo nano /etc/systemd/system/3d-printer-server.service

Add the following to the file:

[Unit]
Description=3D Printer Server After=network.target

[Service]
Type=simple
WorkingDirectory=/home/pi/3D_printer_control Environment=FLASK_APP=/home/pi/3D_printer_control/autoapp.py Environment=XAUTHORITY=/home/pi/.Xauthority Environment=DISPLAY=:0.0
ExecStart=/home/pi/3D_printer_control/env/bin/python /home/pi/3D_printer_control/autoapp.py Restart=always

[Install]
WantedBy=multi-user.target

Reload systemd and start the service with:

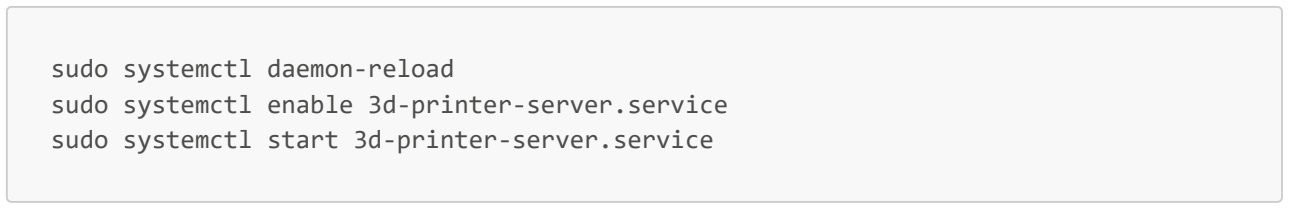
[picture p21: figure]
sudo systemctl daemon-reload sudo systemctl enable 3d-printer-server.service sudo systemctl start 3d-printer-server.service

## Setting custom display resolutions for Visitech

Setup xrandr command on start

Make the autostart folder and entry for our new script.

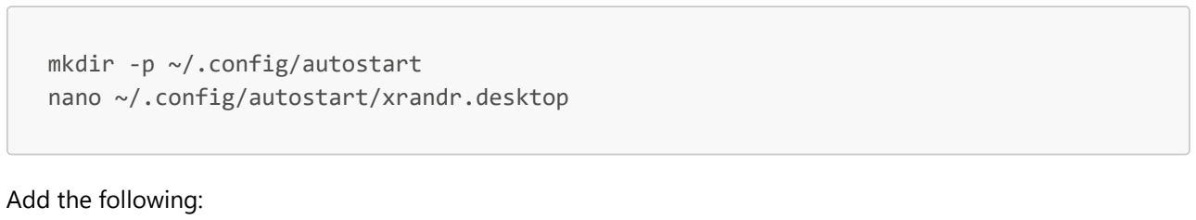
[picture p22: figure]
mkdir -p ~/.config/autostart nano ~/.config/autostart/xrandr.desktop; Add the following:

[Desktop Entry]
Type=Application
Exec=/home/pi/.config/autostart/xrandr.sh Hidden=false
NoDisplay=false
X-GNOME-Autostart-enabled=true Name[en_US]=Xrandr
Name=Xrandr
Comment[en_US]=Set custom resolution using xrandr Comment=Set custom resolution using xrandr

Make our script to set custom resolutions.

nano ~/.config/autostart/xrandr.sh Add the following:

#!/bin/sh

export DISPLAY=:0.0
#xrandr --newmode "2560x1600_30" 132.00 2560 2608 2640 2720 1600 1603 1609 1623 -hsync -vsync # old config (hsync causes grayscale issues)

xrandr --newmode "2560x1600_30" 132.25 2560 2608 2640 2720 1600 1603 1609 1623 +hsync -vsync # based on https://tomverbeure.github.io/video_timings_calculator (CVT-RB)
#xrandr --newmode "2560x1600_30" 132.68 2560 2608 2640 2720 1600 1603 1609 1623 +hsync -vsync # based on edid

#xrandr --newmode "2560x1600_30" 132.6 2560 2608 2640 2720 1600 1602 1604 1625 +hsync -vsync # based on DLPC900 timings

xrandr --addmode HDMI-1 2560x1600_30
xrandr --output HDMI-1 --mode 2560x1600_30

#xrandr --newmode "1920x1080_60" 140.00 1920 1968 2000 2080 1080 1083 1089 1126 -hsync -vsync

xrandr --newmode "1920x1080_60" 148.50 1920 2008 2096 2200 1080 1084 1089 1125 +hsync -vsync
#xrandr --newmode "1920x1080_30" 62.208 1920 1968 2000 2080 1080 1083 1089 1103 -hsync -vsync

xrandr --addmode HDMI-2 1920x1080_60
xrandr --output HDMI-2 --mode 1920x1080_60

xset s off
xset s noblank
xset -dpms

chmod +x ~/.config/autostart/xrandr.sh

You can check the resolutions after a reboot with:

export DISPLAY=:0.0
xrandr

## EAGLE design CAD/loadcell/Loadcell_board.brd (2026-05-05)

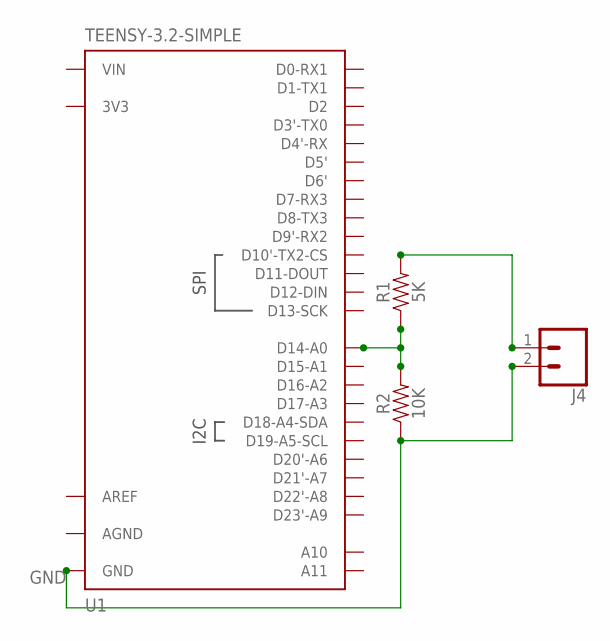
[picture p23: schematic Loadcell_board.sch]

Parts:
J4: CONN_02; 1X02
R1: 5K; AXIAL-0.3
R2: 10K; AXIAL-0.3
U1: TEENSY-3.2-SIMPLE

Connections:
3V3: U1.3.3V (3V3)
AGND: U1.AGND
AREF: U1.AREF
GND: J4.2, R2.P$1 (1), U1.GND
unnamed: R1.P$1 (1), R2.P$2 (2), U1.14 (D14-A0)
unnamed: J4.1, R1.P$2 (2)
VIN: U1.VIN

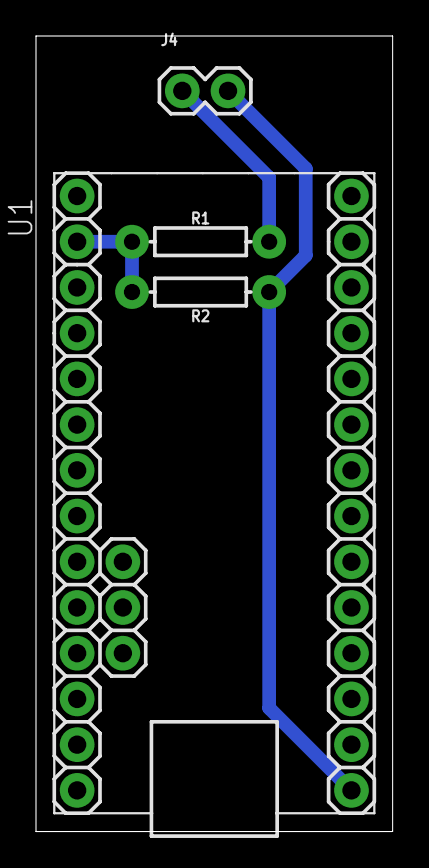
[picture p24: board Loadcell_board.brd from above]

Board: 2 copper layers, 19.8 x 44.2 mm, 4 parts (0 on the bottom side), 3 nets.

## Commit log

2026-05-05 Added CAD
    [5 mm Allen Key Holder.3mf, 5 mm Allen Key Holder.step, Alignment Pin.step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]
2026-05-13 added BOM
    [Bill of Materials.xlsx]
2026-06-08 updated 6/8/26
    [Bill of Materials.xlsx]
2026-07-21 Updated 7/21/26
    [Bill of Materials.xlsx]

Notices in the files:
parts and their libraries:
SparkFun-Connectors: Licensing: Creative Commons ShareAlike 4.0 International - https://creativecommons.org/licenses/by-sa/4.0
